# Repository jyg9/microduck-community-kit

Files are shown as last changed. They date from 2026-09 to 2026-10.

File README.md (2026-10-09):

# 用于Microduck复刻的一些PCB补充

> 这不是官方Microduck仓库，<a href="https://github.com/pollen-robotics/microduck">官方仓库</a>在这里，感谢他们开源。本项目是复刻所需硬件PCB补充。

微信讨论群：

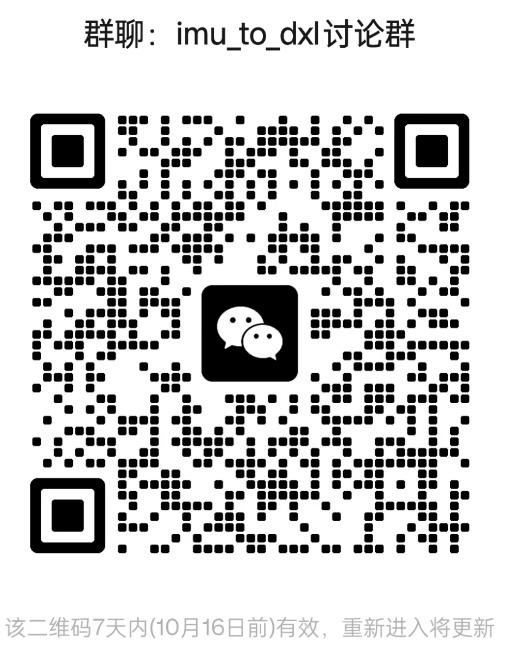
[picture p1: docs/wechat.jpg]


主要包括：
- **imu_to_dxl**：<a href="hardware/imu_to_dxl">身体传感器板</a>、<a href="firmware/v1">对应的固件</a>和<a href="firmware/v1/host">上位机测试软件</a>。特点：高度接近原版设计、高可靠设计、固件可在线升级。
- **banana_pcb**：<a href="hardware/banana_pcb">电池上方的转接小板</a>
- **dxl_hub**：<a href="hardware/dxl_hub">鸭鸭身体中的集线器板</a>
- **飞特舵机调试软件**：<a href="software/hls_servo_debugger">飞特舵机调试软件</a>
- **microduck_feetech**：<a href="https://github.com/jyg9/microduck_ft1910">官方机器人软件（robotd 等）的飞特舵机适配版</a>——官方 `microduck` 的完整参考源码，基于0.16.0打上飞特总线补丁，IMU适配本仓库，可直接编译运行；

接线图：
```text
                               🦆 头部 (Head)
                                    │
                                    │ 舵机线
                                    ▲
 🔋 电池 (Battery)            ┌───────────┐
      │                      │           │
      │ 香蕉头                │  dxl_hub  │
      ▼                      │  (腹部)    │
 🍌 banana_pcb ─────────────>│           │
      (正负电源线)             └─┬───┬───┬─┘
                                │   │   │
                 ┌──────────────┘   │   └──────────────┐
                 │ 舵机线            │ 舵机线            │ 舵机线
                 ▼                  ▼                  ▼
            🦿 左腿            ⚖️ IMU            🦿 右腿
                             (imu_to_dxl，跨部内)
```

如需要编译固件，克隆的时候需要增加--recurse-submodules参数，否则不会下载GDLib：
```bash
git clone --recurse-submodules https://github.com/jyg9/microduck-community-kit.git
```

固件升级方法：
- 1、SFTP复制本项目<a href="firmware/v1/host">主机工具</a>下的`upgrade.py`、`package.py`、`bus.py`到目标电脑。目标电脑可也是鸭子后台，也可以是电脑接USB转舵机TTL。
- 2、从项目Releases下载编译好的固件，两个文件`gd32f303cc_imu_to_dxl_slot_a.ipkg`和`gd32f303cc_imu_to_dxl_slot_b.ipkg`，同样复制到目标电脑。
- 3、执行升级指令：
```bash
# 看目前节点版本号等信息，需不需要升级，提示缺依赖使用pip3 install <包名>安装
./upgrade.py status build/gd32f303cc_imu_to_dxl_slot_a.ipkg

# 升级指令，使用自动识别串口
./upgrade.py upgrade gd32f303cc_imu_to_dxl_slot_a.ipkg

# 升级指令，指定一些参数（高级，与上面二选一）
./upgrade.py upgrade gd32f303cc_imu_to_dxl_slot_a.ipkg --port /dev/ttyS2 --baud 1000000 --protocol auto --yes

# 如果提示slot_a占用，更换上面文件名为slot_b，目前脚本还不是十分智能

# 再检查升级后节点版本，版本号一致就是升级成功
./upgrade.py status
```

## 其他说明
 - 项目主要使用了中国国内易于采购的飞特1910舵机，同时兼容原版XL330
 - 本项目在Linux平台开发，不能保证其他平台兼容性
 - 硬件是纯手工绘制，软件全部由AI编写和调试，已经消耗1G+ Token
 - imu_to_dxl如有需要，可在<a href="https://item.taobao.com/item.htm?ft=t&id=1085185543605">我的店铺</a>购买。
 - 如果觉得项目不错，欢迎小额打赏😀，或者点个星⭐再走？

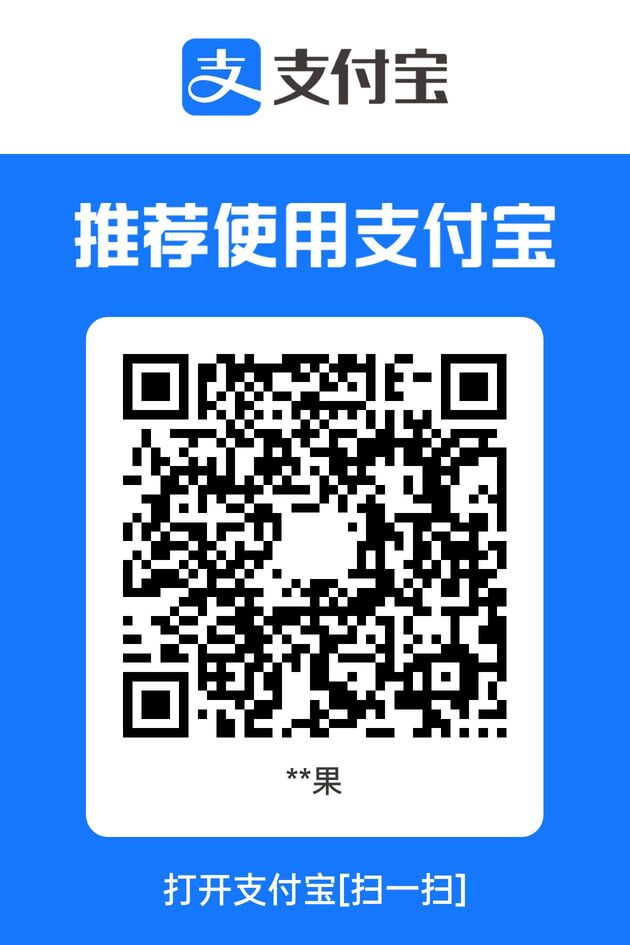
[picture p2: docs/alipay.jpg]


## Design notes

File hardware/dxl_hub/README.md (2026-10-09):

# "dxl_hub" 电力与数据分发板子

> "dxl_hub" 固定在机器鸭身体中舵机上方的板子。用于把电池电力分配到左右腿、头部和IMU。对单总线串口数据信号进行合并。

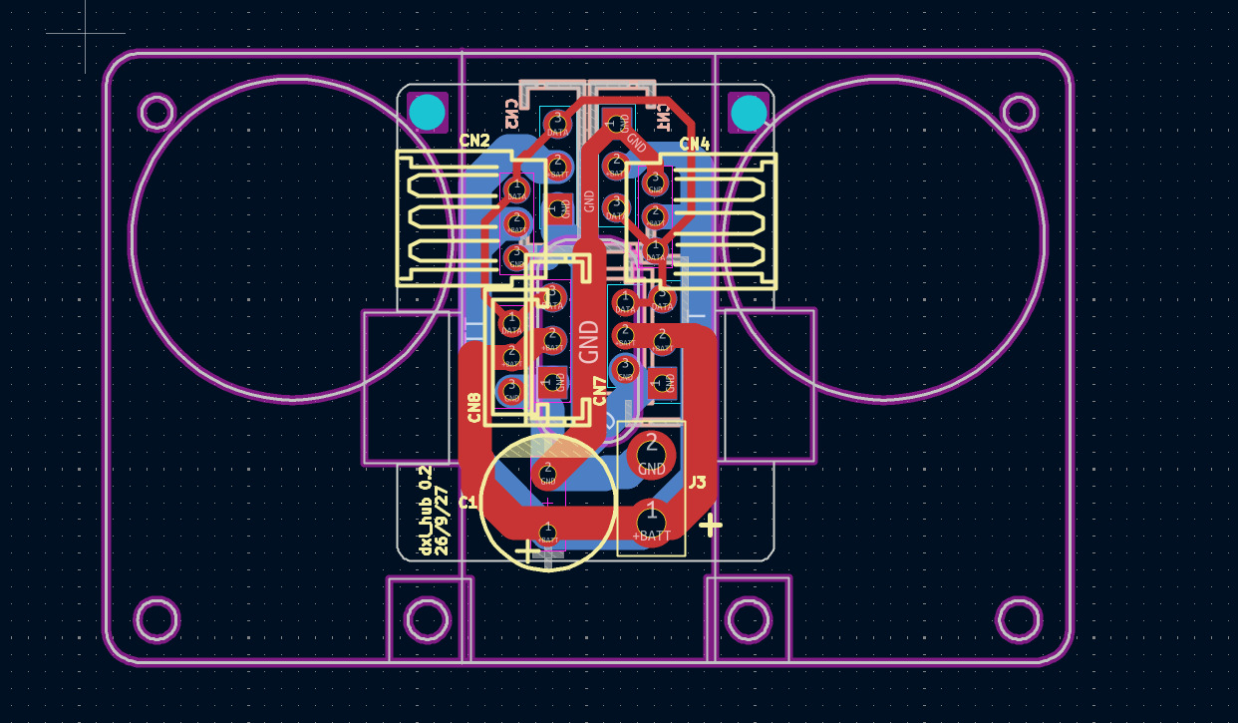
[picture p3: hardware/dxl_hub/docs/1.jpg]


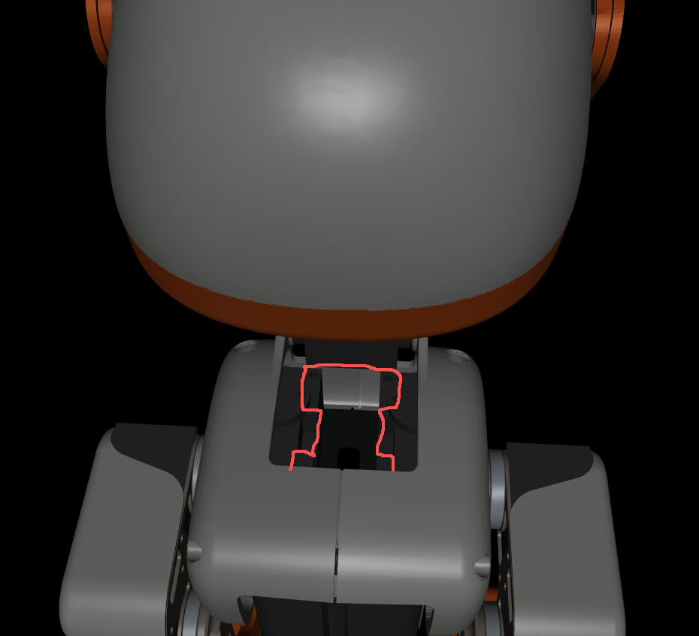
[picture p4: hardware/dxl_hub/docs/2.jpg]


 - 根据需要焊接飞特1910舵机接口或XL330舵机接口，二选一。
 - 三个焊接在背面（两腿+IMU），一个正面（脖子）。
 - 注意：固定到舵机的两颗螺丝，最好用平头，不要用圆头，会有干涉。
 - 插座参考型号：
  - XL330用：B3B-EH-A(LF)(SN)，立式，
  - 飞特1910立式用：A2007WV-3P

## 其他信息
 - 使用KiCAD 9设计。

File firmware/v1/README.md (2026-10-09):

# imu_to_dxl v1 — GD32F303CC 固件

复刻官方未开源的 `imu_to_dxl` 板：把 IMU 姿态数据做成**电机总线上的一个从站节点**，
让机器人控制软件（`microduck` 的 `robotd`）用**同一次 sync_read** 同时拿到 IMU 与全部舵机状态，
主机侧不需要任何额外轮询或融合。

* 主控：GD32F303CC（LQFP48，256 KB Flash / 48 KB SRAM，12 MHz 晶振 → 120 MHz）
* 目标板：`elec_imu_to_dxl/imu_to_dxl`，**PCBA 已回板并烧写**（bootloader + slot A），
  节点 ID 200 挂在 1 Mbps 半双工伺服总线上（USART1，PA2/PA3）
* 真板传感器：**LSM6DSV16X**（SPI0：PA4=CS / PA5=SCK / PA6=MISO / PA7=MOSI，INT1/INT2 = PB0/PB1），
  由 `IMU_USE_SPI=1`（默认）选 `src/imu_spi.c` + `src/lsm6dsv16x.h`；`=0` 时回到模拟器 `src/imu_sim.c`
* 台架拓扑：PC 经 USB 串口适配器接**电机总线**（USART1，PA2/PA3；15 颗 HD-1910-C001：右腿 10-14、
  左腿 20-24、颈/头/嘴 30-34），适配器通常枚举成 `/dev/ttyACM0`（换 USB 口后先 `ls /dev/ttyACM*` 确认）；
  调试口是 CH340 的 `/dev/ttyUSB*`（USART0，PB6/PB7，115200，**只输出 `DBG_*` 日志、不承载任何协议**）
* 两种协议：**Dynamixel 2.0**（ID 200，地址 124）与**飞特 SCS/HLS**（ID 200，地址 56），节点自动识别
* 上位机：`host/`（本地网页版，3D 姿态 + 实时瀑布流 + 抖动/偏移统计）

> 相关文档
> * `docs/dynamixel_slave.md` —— Dynamixel 从站实现细节与寄存器表（含 2.0 字节填充）
> * `docs/flash_layout.md` —— Flash 分区 / bootloader / 总线升级协议设计（待实现）
> * `docs/lsm6dsv16x_driver_spec.md` —— 真 LSM6DSV16X 驱动规格（含 §8.1 CONVERGE 实现状态）
> * `docs/bus_timing_borrow_plan.md` —— 总线时序风险分析 + 借鉴计划（**已实施**；真机缺陷见 §4.6，真机验证见 §7）
> * `patches/README.md` —— 官方 `microduck` 仓库飞特补丁说明（补丁文件同目录；原名 `microduck_feetech_patch.md`，`2fc4731` 改名）
> * `../../software/microduck_feetech/` —— 打好该补丁的官方 `microduck` 完整源码（可直接编译运行 `robotd`）
> * `../../docs/飞特通讯协议说明.md` —— 飞特协议完整说明
> * `host/README.md` —— 上位机使用说明

---

## 1. 当前状态（诚实清单）

| 功能 | 状态 | 验证方式 |
|---|---|---|
| 系统时钟 120 MHz（12 MHz 晶振） | ✅ | 上板运行（LED 心跳 + 串口 banner） |
| Dynamixel 2.0 从站（PING/READ/WRITE/REG/SYNC_READ/SYNC_WRITE/**FAST_SYNC_READ 0x8A**/BULK_READ/RESET/REBOOT/CLEAR） | ✅ | `host/tools/test_protocols.c` 逐字节比对 rustypot 参考向量；`host/tools/rustypot_check/` 再用**真的 rustypot 1.8 解析器**对拍 |
| Dynamixel 2.0 `0x8A` 聚合应答（`ID=0xFE`、不填充、逐段累积 CRC、按字节数让位） | ✅ | C 测试（含 e-manual 32 字节向量与 `FF FF FD` 反证）+ 真机 `host/tools/fast_sync_read_check.py`（19 项，见 `docs/imu_to_dxl_protocol.md` §11(c2) 与 `docs/bus_timing_borrow_plan.md` §7.8）；真 XL330 同总线未验证，见 `docs/imu_to_dxl_protocol.md` §15.5 第 11 项 |
| Dynamixel 2.0 字节填充（`FF FF FD`） | ✅ | 同上 + `src/stuffing.c` 单元测试（rustypot 1.6 会解填充） |
| 飞特 SCS/HLS 从站（PING/READ/WRITE/REG/ACTION/RECOVERY/**REBOOT 0x08**/RESET/CAL/SYNC_READ/SYNC_WRITE） | ✅ | 同上 + `host/bus.py` 自检 |
| 协议自动识别 + 粘滞 + 可锁定 | ✅ | `host/tools/bus_smoke.py`（上板后可跑） |
| 模拟 IMU（7 种模式，四元数与陀螺自洽） | ✅（`IMU_USE_SPI=0`） | C 测试：陀螺/四元数导数一致性、半精度、安装矩阵往返 |
| **真 LSM6DSV16X SPI 驱动（`src/imu_spi.{c,h}` + `src/lsm6dsv16x.h`）** | ✅ 已实现 + 真机验证 | `bus_smoke.py` 真传感器路径 + `host/tools/sensor_probe.py`；见 §8.6 |
| **`IMU_USE_SPI` 构建开关（默认 1 = 真驱动，0 = 模拟器）** | ✅ | `src/board.h`、`CMakeLists.txt` |
| 寄存器镜像（XL330 控制表 + HLS 内存表 + 厂商窗口） | ✅ | C 测试 + 上位机读写 |
| 片上温度 / 实时 tick / 状态位 | ✅ | 寄存器读取 |
| 调试串口（可宏关闭、运行时可调级别） | ✅ | 上板（banner + 2 s 周期统计） |
| USART1 电机总线 + USART0 只输出日志的调试口 | ✅ | 见 §5；协议与升级只走总线（PC 侧通常 `/dev/ttyACM0`）；镜像口是默认关闭的台架选项 |
| 配置存 Flash（ID/波特率/模拟参数） | ✅ | `src/dev.c`（最后一页 + CRC16） |
| 上位机网页版（3D + 瀑布流 + 统计 + 录制 CSV） | ✅ | HTTP/WS 集成测试 + 前端桩测试（见 §7） |
| **bootloader（32 KB）+ A/B slot 启动决策** | ✅ 已实现 | `host/tools/test_boot.c`（决策表全表）+ 真机启动 A/B/回滚 |
| **电机总线串口升级（块 CRC + 两段镜像 CRC32 + trial/回滚）** | ✅ 已实现 | `host/tools/test_boot.c` + `host/tools/test_upgrade.py`（pty 端到端）+ 真机 3 次升级 |
| **Linux 升级工具（包校验 / 版本比较与提示 / 升级 / 回读）** | ✅ 已实现 | `host/upgrade.py`，见 `docs/upgrade.md` |
| **sync_read 位次仲裁（答在自己的槽里）** | ✅ 已实现 + 真机验证 | 真机 1/2/3 个前导 ID → +339/+676/+1001 µs；`test_protocols.c` 的 `bus_arb` 用例 |
| **中断解析 + DMA 应答（T_resp 有界）+ 原子遥测发布** | ✅ 已实现 + 真机验证 | 双协议冒烟 2555 次轮询、0 超时 0 坏帧；`bus_arb`/`telem_pack` 主机用例 |
| **FeeTech 15 字节契约块（56）+ 20 字节诊断块（native 128 / ft6 124）** | ✅ 已实现 + 真机验证 | `bus_smoke.py`：56/15、byte14=0、计数递增、与别名一致（native 128，ft6 196） |
| microduck 飞特补丁 | ✅ 已编译 + 单测（93 项） | `patches/microduck-feetech.patch` |

**已在真硬件上实测**：协议（两种）、bootloader 启动决策、总线升级（3 次，含 trial
自确认与 3 次未确认回滚）、升级前后协议冒烟全过 —— 记录见 `docs/upgrade.md` §8。
时序改造（位次仲裁 / 中断+DMA 应答 / 契约块）有一轮真机验证（`docs/bus_timing_borrow_plan.md` §7）；
真 PCBA + 真 LSM6DSV16X + 15 颗舵机的一轮见本文 §8.6 与计划文档 §7.6/§7.7。

**真硬件已验证（2026-09-25）**：真 LSM6DSV16X（`WHO_AM_I`=0x70、SPI0 mode 0 @7.5 MHz、
静止 996–997 mg、`|q|`=1.0000、四元数重力 vs 加速度 0.05–0.12°、陀螺零偏 (−0.97,+0.16,+0.73) dps）、
与 15 颗舵机共总线（16 ID `sync_read` 150/150 扭矩开/关、背靠背 200/200）、
真机联调修掉的三个固件缺陷（回声窗口 / µs 时钟回绕 / SFLP CONVERGE，见计划文档 §4.6）。

**仍未在真硬件上验证的部分**：绝对 T_resp（要示波器/逻辑分析仪，宿主 USB 时间戳只到 ~0.3 ms）；
本节点排在 `sync_read` ID 列表中间/末尾时的让位（运行时 200 固定第 0 位）；
满槽 96 KB 升级与擦除中途掉电演练。（主机侧 `robotd` 突发截断曾列在此处，**2026-10-02 已修**：
删 `tcdrain` + `BURST_IDLE` 2 → 4 ms，见 `docs/bus_timing_borrow_plan.md §7.7`。）

---

## 2. 硬件与引脚

| 引脚 | 功能 | 说明 |
|---|---|---|
| PA2 / PA3 | USART1 TX / RX | **电机总线**（单线半双工）。节点与 15 颗舵机共用，全部寄存器协议流量与现场升级只在这里（PC 侧 USB 串口适配器，通常 `/dev/ttyACM0`）。方向控制由硬件从 TX 自动产生（原理图里的 `TXD_EN`，Q1+R28/R29/C22），固件不控制任何 GPIO |
| PA4 | SPI0_NSS | IMU 片选（低有效）；`IMU_USE_SPI=1` 时由 `src/imu_spi.c` 驱动，传输间保持高 |
| PA5 / PA6 / PA7 | SPI0_SCK / MISO / MOSI | IMU SPI，`IMU_USE_SPI=1` 时是 LSM6DSV16X 总线（mode 0 @ 7.5 MHz）；`=0` 时浮空不用 |
| PB0 / PB1 | IMU INT1 / INT2 | LSM6DSV16X 上拉输入；驱动轮询，但已把 FIFO 水位/溢出路由到 INT1，留给将来中断或示波器 |
| PB6 / PB7 | USART0 TX / RX | **只输出调试日志**的串口（CH340，PC 侧 `/dev/ttyUSB*`，115200），不解析、不应答任何协议帧；`BUS_MIRROR_ENABLE=1` 时才是台架镜像口（见 §5） |
| PB5 | 状态 LED（开发板） | 1 Hz 心跳；5 s 没收到总线帧则 8 Hz 闪（提示"没有主机在说话"） |

时钟：`(HXTAL / 2) * 20 = 120 MHz`。**注意** GD32 官方 `system_gd32f30x.c` 默认按 8 MHz 晶振
硬编码 `RCU_PLL_MUL30`，在 12 MHz 板上会算成 180 MHz 而卡死；本工程自带一份可选时钟源的副本
（`src/system_gd32f30x.c`），`HXTAL_VALUE` 也必须通过 CMake 传成 12 MHz，否则波特率会错。

---

## 3. 遥测块（与官方板一致）

20 字节诊断块，两种协议的**内容**相同，但 FeeTech 的 56 处只暴露前 15 字节（见 §4）：

| 字节 | 内容 | 单位 |
|---|---|---|
| 0~5 | 陀螺 x/y/z，i16 小端 | ±500 dps，**17.5 mdps/LSB** |
| 6~11 | 四元数 x/y/z，IEEE half（binary16） | `w = √(1-x²-y²-z²)` |
| 12~17 | 加速度 x/y/z，i16 小端 | ±4 g，0.122 mg/LSB |
| 18 | 采样计数（u8，回绕） | 100 Hz |
| 19 | 状态位 | `0x01` SFLP 有效（本块带四元数）/ `0x02` 计数回绕 / `0x04` 陀螺饱和 / `0x08` 传感器错误 / `0x10` 模拟数据 / `0x20` 冻结 / `0x40` 配置未保存 / `0x80` 融合算法**正在运行**（`FUSION_OK`，不等于已收敛） |

控制环只读**前 12 字节**（陀螺 + 四元数 xyz）——这正是官方板"与舵机共用地址、塞进同一事务"的做法。

**FeeTech 侧的"契约块"（重要）**：真舵机在地址 56 起只答 **15 字节**
（位置/速度/负载/电压/温度/状态/移动/电流），而运行时的 `sync_read` 对 IMU 节点和 15 颗舵机
用的是**同一个长度**。所以本节点在 56 处也回答 15 字节：
`12 字节控制块 + 采样计数(12) + 状态位(13) + 保留 0(14)`（`src/telem_pack.c`），
**加速度搬到 20 字节诊断块的别名**（native 在 128；ft6 人格在 196，见 `docs/imu_to_dxl_protocol.md` §16）。选 15 而不是 20 是量出来的：每多 5 字节 × 16 个设备
就要多约 0.8 ms 总线时间（见 `docs/bus_timing_borrow_plan.md` §2、§7）。

**坐标系**：板子安装使 `躯干系 = [+raw_z, +raw_y, −raw_x]`（绕 Y 轴 +90°）。
固件上报的是**芯片系**数据，主机用 `microduck` 的 `DEFAULT_MOUNT = [1/√2, 0, 1/√2, 0]`
左乘/右乘还原（`q_trunk = q_raw ⊗ mount⁻¹`，`ω_trunk = mount · ω_raw`）。
调试时可用厂商寄存器 `REPORT_FRAME=1` 让固件直接上报躯干系（主机就不要再转）。

**已知偏差**：真板存在约 5° 的系统性 pitch 偏置，由 runtime 在源头校正（见 `microduck` 注释）。
上位机 3D 视图会显示重力与"世界竖直"的夹角，可用来测这个偏置。

---

## 4. 两种协议下的地址映射

| | Dynamixel 2.0 | 飞特 SCS/HLS |
|---|---|---|
| 帧结构 | `FF FF FD 00 ID LEN_L LEN_H INST ... CRC16`（ROBOTIS CRC-16，**含帧头**；状态帧带 `0x55` 标记；**参数区字节填充**） | `FF FF ID LEN INST [ADDR] DATA ~SUM`（8 位取反和；无填充） |
| 节点 ID | 200（寄存器 7，可改并持久化） | 200（寄存器 5，可改并持久化，禁止 0xFD） |
| 遥测块地址 | **124**（`present_pwm` 起 20 字节，前 12 是控制环要的；两种 FeeTech 人格下都一样） | **56**（`PRESENT_POSITION_L` 起 **15** 字节：12 控制 + 计数 + 状态 + 保留 0）；完整 20 字节诊断块在 **128**（native）/ **196**（ft6） |
| 波特率 | 1 Mbps（寄存器 8 = 3） | 1 Mbps（寄存器 6 = 0） |
| 每次调度读的地址/长度 | `124` / 12（主机可读 20 拿诊断尾部） | `56` / **15**（与 15 颗舵机同一次 `sync_read`，长度必须对所有设备成立） |
| 厂商配置窗口 | **148~167**（20 字节） | **160~179**（同一张表） |
| 设备语义 | 状态返回级别(68)、只读区拒绝写入 | 应答状态级别(8，默认 1)、锁标志(55，默认 0=可持久化)、角度限位/死区/偏移等 |
| 只读信息 | 型号 1200（`0x04B0`）、固件版本 0x10 | 固件版本 1.0（寄存器 0/1）、型号 `0x4D49`（'I','M'，**故意不是舵机型号**） |
| 应答 STATUS 字节 | 按协议（`DXL_ERR_*`，rustypot 会解码） | **恒 0**（飞特工具会把非 0 当舵机故障）；最近一次内部错误放厂商窗 `V_LAST_ERR`(179) |
| 5 V / 诊断 | 144~146（电压、温度） | native：128~147（诊断块 + 别名）；ft6：124~143（诊断块）+ 196~215（别名）；71~75 不参与契约，保持 0 |

飞特侧另外按厂商手册实现了两个容易被忽略的语义：寄存器 8（应答状态级别，写 0 后写指令执行但静默、
读指令仍应答）与寄存器 55（锁标志，加锁时写入仍生效但不持久化——手册里它是"是否掉电保存"，不是"是否允许写"）。
两项都有上板回归（`host/tools/bus_smoke.py` 的 `device semantics` 段）。

**协议自动识别**：一帧的第 3 字节为 `0xFD` → Dynamixel 2.0；否则 → 飞特。
成功应答一种协议后，该端口 100 ms 内只认这种协议（`BUS_PROTO_STICKY_MS`），
避免把数据里的 `FF FF <本机ID>` 误判；厂商寄存器 `PROTO_LOCK`（0 自动 / 1 仅 DXL / 2 仅飞特）可强制。

**位次与应答时序（实测，见 `docs/bus_timing_borrow_plan.md` §7）**：真舵机在 `sync_read`
里会为**每一个排在它前面的 ID** 等一个"应答槽"（实测 ≈295 µs，前导设备缺席也照样占一槽）。
本节点在 ID 列表里的下标 k > 0 时，会先让出 k 个槽再应答（`src/bus_arb.c`）；运行时 IMU 节点
固定排第 0 位，所以那条热路径是"收完指令立刻发"。应答的解析在 USART 中断里、
发送走 **DMA**（USART0_TX = DMA0 CH3，USART1_TX = DMA0 CH6），因为排在后面的设备
只留 ≈295 µs，主循环给不出这个上界。

**FeeTech `0x08` REBOOT（实测补充，见计划文档 §1.7）**：这颗 HD-1910（fw 3.46）**支持** 0x08——
**不应答**、约 **823 ms** 回来、ID/波特率/模式/锁/OFS 全保留、**RAM 增益(50/51)回落到 EEPROM(21/22)**
（正是 `RobotIo::reboot` 契约要的语义）。本节点的飞特人格据此实现 0x08（不应答地重启，
应用与 bootloader 共用 `dev_request_reboot()`）；主机补丁的 `reboot()` 也从"明确不支持"
改成"先写扭矩 0、发 0x08、不等应答立即返回"。

---

## 5. 调试口（只输出日志）与电机总线

**电机总线是 `USART1`（PA2/PA3）**：节点和 15 颗舵机共用它，单线半双工；所有寄存器协议流量
（Dynamixel 2.0 / 飞特）与**现场升级**都只在这条总线上发生，别处没有。PC 侧是 USB 串口适配器，
通常枚举成 **`/dev/ttyACM0`**（ACM 编号跟着适配器枚举走，换 USB 口/插别的设备后先
`ls /dev/ttyACM*` 确认）；`host/`、`./build.sh smoke` 与 `host/upgrade.py` 都默认用它。

**调试口是 `USART0`（PB6/PB7）**：CH340，PC 侧是 `/dev/ttyUSB*`，115200，**只输出日志**，
不承载任何协议——它不解析、也不应答协议帧，所以终端上敲的东西不会被当成总线帧。
日志行以 `#` 开头、ASCII 里没有 `0xFF`（主机分帧器可以安全地在文本里重新同步）。

* `BUS_MIRROR_ENABLE`（`src/board.h`、`CMakeLists.txt`）现在**默认 0**，上面就是默认行为。
* 只有在"开发板上电机总线还没接"的**台架**场景才把它设为 1：此时 `USART0` 临时兼作第二个
  协议口（1 Mbps，波特率编码见 §6 的 `MIRROR_BAUD`），方便一块板子上同时看调试文本与协议。
  注意这时的 `USART0` **什么都能做，包括升级**——协议层不区分端口。所以升级工具
  `--port` 默认指向电机总线（`auto` 会打印它选了哪个设备，见 `docs/upgrade.md` §4.5），
  不要指到调试口上去。
* 升级端口由**工具**负责选对：默认 `--port auto` **逐个探测** `ttyACM0-1`、
  `ttyUSB0-5`、`ttyS2` 里存在的设备，取第一个真的能应答节点的那个并打印它选了谁
  （存在的 `ttyUSB*` 不会被按名字排除：它既可能是总线适配器，也可能是调试口，
  按"能不能应答"判断）；同时**拒绝和另一个主机抢端口**（机器人上那是 robotd，
  工具会打印 stop/upgrade/start 三行提示）。见 `docs/upgrade.md` §4.5。

`./build.sh` 现在会在配置之后打印**有效的缓存选项**（`APP_SLOT APP_VERSION_STR BOOT_ENABLE
DBG_ENABLE BUS_MIRROR_ENABLE IMU_USE_SPI`），`BUS_MIRROR_ENABLE=1` 时还会加一条 NOTE。
CMake 的缓存会跨源码更新保留旧值，所以老的 `build/` 目录可能仍是台架镜像构建：
如果摘要里是 1，用 `./build.sh clean`（或 `-DBUS_MIRROR_ENABLE=0`）重新配置。

**调试口的物理引脚**（这块 PCBA 上是一个 4 pin 排针 **H1**；网表见 `hardware/imu_to_dxl`）：

| H1 引脚 | 信号 | 说明 |
|---|---|---|
| 1 | `+3.3V` | |
| 2 | `GND` | |
| 3 | `DEBUG_RX` | **PB7**，经串阻 R10，R7 上拉到 3.3V |
| 4 | `DEBUG_TX` | **PB6**，经串阻 R11 |

**PC 侧适配器的 TX 必须接到 H1-3**。只接 GND + TX 的"两根线"接法能读到日志（TX 一路是通的），
但节点收不到任何字节——日志里 `uart0 rx=0` 就是它的表现，`BUS_MIRROR_ENABLE=1` 的台架镜像模式
也就无从谈起（这一点在真板上实测确认过）。

---

## 6. IMU：真驱动与模拟器

`IMU_USE_SPI`（`src/board.h`、`CMakeLists.txt`，默认 **1**）选择传感器来源：

* **1 = 真 LSM6DSV16X**：`src/imu_spi.c` + `src/imu_spi.h` + `src/lsm6dsv16x.h`，
  SPI0（PA4–PA7），mode 0 @ 7.5 MHz，芯片自己做 SFLP 融合；`src/imu.c` 是门面并拥有 10 ms 采样网格。
* **0 = 模拟器**：`src/imu_sim.c` 用**同一条角速度**既积分四元数又生成陀螺计数，
  保证上报的陀螺与四元数严格自洽（这样才能真正验证上位机的 3D 视图与瀑布流，而不是看随机数）。

模拟器模式（仅 `IMU_USE_SPI=0` 的构建生效）：

| `SIM_MODE` | 名称 | 用途 |
|---|---|---|
| 0 | static | 静止 + LSB 级噪声：看抖动底噪 |
| 1 | sine | 三轴正弦（默认）：看 3D 姿态与瀑布流是否正常 |
| 2 | drift | 慢速偏航 + 注入陀螺偏置：看"偏移/漂移" |
| 3 | noise | 宽带陀螺噪声：看抖动与统计 |
| 4 | spin | 快速自转 |
| 5 | sflp-wait | 陀螺正常但四元数字节全 0：验证"保持上一有效值 / ready 门控" |
| 6 | frozen | 每次读出完全相同：验证 `microduck` 的 stale 检测 |

厂商窗口（20 字节，DXL 148 / 飞特 160）：

| 偏移 | 名称 | 读/写 | 说明 |
|---|---|---|---|
| 0~1 | MAGIC | RW | `0x4D49`（'I','M'）；写窗口时用于判断有效性 |
| 2 | CMD | W | 1 保存配置 / 2 恢复出厂 / 3 重启 / 4 重启运动模型（执行后自动清 0） |
| 3 | SIM_MODE | RW | 上表 0~6 |
| 4~5 | SIM_AMP | RW | 幅度千分比 100~5000（默认 1000） |
| 6~7 | SIM_FREQ | RW | 频率千分比 100~5000（默认 1000） |
| 8 | REPORT_FRAME | RW | 0 芯片系（默认，与真板一致）/ 1 躯干系 |
| 9 | PROTO_LOCK | RW | 0 自动 / 1 仅 Dynamixel / 2 仅飞特 |
| 10~15 | GYRO_BIAS_X/Y/Z | RW | i16，直接叠加到上报的陀螺原始计数（注入偏移或在线标定） |
| 16 | MIRROR_BAUD | RW | USART0（调试口 / 台架镜像口）波特率编码（飞特编码表）。`BUS_MIRROR_ENABLE=0` 时 USART0 固定 115200 调试口；此寄存器与电机总线（USART1）无关 |
| 17 | DBG_LEVEL | RW | 0 关 / 1 仅错误 / 2 启动+2 s 统计（默认）/ 3 每帧跟踪 |
| 18 | STATUS | R | bit0 配置未保存 / bit1 来自 Flash / bit2 使用模拟数据 |
| 19 | LAST_ERR | R | 最近一次被拒绝的协议操作（`DXL_ERR_*`）。应答 STATUS 恒 0，所以原因只能从这里问 |

配置（ID / 波特率 / 模拟参数）写入后**先等寄存器写入平静 500 ms，再等总线安静 1.5 s**，
才落 Flash 最后一页（`0x0803F800`，`CFG_FLASH_ENABLE=0` 可关）——
因为擦一页 Flash 会让内核（以及 USART 中断）停顿几十毫秒，在机器人持续轮询时保存会吃掉一个控制周期。
显式的 `CMD=1`（保存）是立即写，主机需要容忍那一次读超时。`CMD=2` 恢复出厂。

厂商窗口的 `STATUS`(18) 与 `LAST_ERR`(19) 可以写（整窗口 20 字节一次写入不会被拒），但写入无效——
主循环发布寄存器镜像时（`dev_refresh()`）会用真实状态覆盖它们。**寄存器镜像现在由主循环发布，
读取本身不再触发刷新**：读发生在 USART 中断里（见 §4 的时序段），那里不能做 ADC 转换或重写厂商窗。
发布在一段很短的临界区里完成，所以中断读到的是"整块新"或"整块旧"，不会读到半新半旧的四元数。

---

## 7. 编译、烧录与测试

```bash
cd v1

# 1) 构建（arm-none-eabi-gcc + cmake，无需网络）
./build.sh

# 1b) 1) 里的构建已经是 FT6 人格（默认）+ 本板朝向补偿，直接给 R17 机器人用。
#     要出 native（社区主机）镜像，另用一个 BUILD_DIR 显式指定：
BUILD_DIR=build-native EXTRA_CMAKE_ARGS="-DFEE_IMU_PERSONALITY=native" ./build.sh

# 2) 烧录（J-Link，设备名必须是 GD32F303CC，不能带封装后缀 T6）
./build.sh flash              # APP_SLOT 镜像（开发板构型，会覆盖 bootloader 区）
./build.sh flash-pair a       # 量产构型：一次擦除 + bootloader + slot A（推荐）
./build.sh flash-boot         # 只更新 bootloader（整片擦除）
./build.sh flash-slot b       # 只替换 slot B（不擦除，保留 bootloader）
./build.sh erase / reset

# 3) 全部主机测试（纯 gcc + Python，不需要硬件）
./build.sh test
#    -> CRC 对拍、两个协议从站、bootloader 决策表/flash 策略/升级状态机（9500+ 断言）
#    -> 寄存器镜像：native 金标逐字节比对 + ft6 人格布局 + 两种人格 DXL 镜像相同
#    -> 升级包格式 + 升级工具 pty 端到端（173 断言）+ 编解码/服务自检
host/tools/run_c_tests.sh                          # 只跑 C 部分
../.venv/bin/python host/tools/test_upgrade.py     # 只跑升级工具端到端

# 4) 上板协议冒烟测试（需要串口；真/模拟两条路径，脚本读 TELEM_FLAG_SIMULATED 自动选）
./build.sh smoke
BUS_PORT=/dev/ttyACM0 BUS_BAUD=1000000 ./build.sh smoke      # 电机总线口（先 ls /dev/ttyACM* 确认编号）
BUS_PORT=/dev/ttyUSB0 BUS_BAUD=1000000 ./build.sh smoke      # 仅台架镜像构建（BUS_MIRROR_ENABLE=1）

# 4b) 真舵机只读探针（PING/READ/SYNC_READ，绝不写；见 docs/bus_timing_borrow_plan.md）
./host/tools/py.sh host/tools/servo_probe.py --port /dev/ttyACM0 --repeat 21

# 4c) 真 LSM6DSV16X 只读表征探针（四元数/加速度/重力夹角/零偏/SFLP 重启；见 §8.6）
./host/tools/py.sh host/tools/sensor_probe.py --port /dev/ttyACM0

# 4d) Fast Sync Read（0x8A）验收：本机在第 0 位 / 第 1 位 / 未被点名三种位置
./host/tools/py.sh host/tools/fast_sync_read_check.py --port /dev/ttyACM0
./host/tools/py.sh host/tools/fast_sync_read_check.py --self-test       # 不需要硬件

# 4e) 与官方 rustypot 解析器对拍（需要 Rust 工具链，故不在 ./build.sh test 里）
cd host/tools/rustypot_check && cargo run --release && cd -

# 5) 现场升级（详见 docs/upgrade.md）
./build.sh status  build/gd32f303cc_imu_to_dxl_slot_b.ipkg    # 需不需要升级？
./build.sh upgrade build/gd32f303cc_imu_to_dxl_slot_b.ipkg --yes
./host/upgrade.py verify <pkg>                                # 只校验包

# 6) 打开上位机（浏览器访问 http://127.0.0.1:8081）
./build.sh host
```

可选编译项（`EXTRA_CMAKE_ARGS` 或 `-D` 传入）：

| 变量 | 默认 | 说明 |
|---|---|---|
| `APP_SLOT` | 0 | 0 = 链接到 0x08000000（开发板，无 bootloader）；1/2 = A/B slot（并设置 VTOR） |
| `BOOT_ENABLE` | 1 | 1 = 同时构建 bootloader 与 A/B 两个 slot 镜像 |
| `APP_VERSION_STR` | 按人格 | 打进镜像头与升级包的版本号（`major.minor.patch`，只能是数字）。native 默认 `1.5.1`、ft6 默认 `1.6.0`；两种人格必须不同，否则升级工具会拒绝或静默替换人格 |
| `DBG_ENABLE` | 1 | 0 = 完全去掉调试输出代码 |
| `BUS_MIRROR_ENABLE` | 0 | **默认 0**：USART0 只做调试口（只输出日志）。1 = 台架选项（开发板尚未接电机总线时让 USART0 兼作协议口），升级会话仍只在电机总线上开放 |
| `IMU_USE_SPI` | 1 | 1 = 真 LSM6DSV16X（`src/imu_spi.{c,h}` + `src/lsm6dsv16x.h`）；0 = 模拟器（`src/imu_sim.c`） |
| `FEE_IMU_PREMOUNT` | `0,0,0,1`（ft6） | ft6 人格专用：给飞特侧 12 个控制字节加的**芯片系**预旋转 `"w,x,y,z"`。默认 `0,0,0,1` = 本板 IMU 芯片相对原 FT6 节点绕封装法线翻转 180°（X、Y 反向、Z 不变），因此主机侧标定可以保持出厂值；`1,0,0,0` = 不转（与原节点同向时用）。Dynamixel 侧不受影响 |
| `FEE_IMU_PERSONALITY` | ft6 | FeeTech 侧线协议人格：`ft6` = 与 R17 主机的 FT6 节点逐字节兼容（**默认**，R17 机器人用这个）；`native` = 本仓库自己的契约。**只影响 FeeTech 侧**，Dynamixel 协议 2.0 两种人格完全相同。两种人格的镜像在总线上不通用，请各用一个 `BUILD_DIR`（详见 `docs/imu_to_dxl_protocol.md` §16） |
| `STATUS_LED_ENABLE` | 1 | 0 = 无 PB5 心跳灯 |
| `CFG_FLASH_ENABLE` | 1 | 0 = 不写 Flash（配置只存 RAM） |
| `TEMP_SENSOR_ENABLE` | 1 | 0 = 不读片内温度（固定 30 °C） |
| `SYS_CLK_SOURCE` | HXTAL | IRC8M 可绕过晶振问题 |
| `SYS_CLK_HXTAL_HZ` | 12000000 | 晶振频率，同时定义 `HXTAL_VALUE` |

当前占用（Release，`-Os`，`IMU_USE_SPI=1` 真机构建，2026-09-25 实测）：

| 目标 | FLASH | RAM |
|---|---|---|
| 应用（开发镜像，`APP_SLOT=0`） | **24036 B / 254 KB** | **8288 B / 48896 B (16.95%)** |
| 应用（slot 镜像，96 KB 槽） | **24600 B / 96 KB (25.0%)** | 8288 B |
| **bootloader** | **18764 B / 32 KB (57.3%)** | 8288 B + 8 B（`.boot_ram`） |

（以上为 2026-09-25 `./build.sh` 构建（`IMU_USE_SPI=1`）的实测大小；RAM 百分比按链接脚本的
48896 B `RAM` 区算，另有顶部 256 B `BOOTRAM` 握手区。P0/P1 时序改造那一轮的旧数字是
dev 26.1 KB / slot 26.7 KB (28%) / boot 18.7 KB (58%)，见 `docs/bus_timing_borrow_plan.md` §7.5。）

比改造前各多约 1.6–1.8 KB flash、1.1 KB RAM：应答要走 DMA（每个端口一份应答缓冲 +
一份延迟缓冲）、要 µs 级时基（DWT）、要位次状态机与契约块打包，外加真 LSM6DSV16X 驱动
（SPI0 与 CONVERGE 状态）。bootloader 也带同一套（boot 模式下协议行为与应用完全一致）。

`.boot_ram` 是 SRAM 顶部 256 字节里唯一的 8 字节握手区（NOINIT，启动代码不清），
所以 RAM 区在链接脚本里被拆成 `RAM`（48896 B）+ `BOOTRAM`（256 B）两块，并有
`ASSERT(_sp <= 0x2000BF00)` 防止栈越界踩到它。

> ⚠️ J-Link 与串口设备（电机总线 `/dev/ttyACM*`、调试口 `/dev/ttyUSB*`）在受限沙箱里不可见；
> 烧录与串口测试需要在能访问 USB 的环境执行。

### 7.1 A/B 构型与现场升级（一句话版）

量产构型是 **32 KB bootloader + 两个 96 KB 应用槽（A/B）**：bootloader 校验两个槽的
镜像头（魔数/长度/entry/两段 CRC32/板号），按 `boot_slot` 与 trial 状态选一个跳转；
新镜像先以 **trial** 启动，30 s 内没有自我确认就在 3 次尝试后**自动回滚**。
升级通过电机总线完成（复用两种协议，不新增帧类型；调试口 USART0 不参与升级，见 §5；
机器人上这条总线是 `/dev/ttyS2`，升级前先 `sudo systemctl stop robotd` 让出总线），
由 `host/upgrade.py` 驱动：

```
verify  → 校验升级包（容器 CRC32 + 镜像头 + 两段 CRC32，坏包不上线）
status  → 读节点身份窗（模式/槽/版本/镜像 CRC/启动状态）+ 版本比较与提示
upgrade → VCMD_BOOT 进 bootloader → 分块写（块 CRC + 序号 + 回读）→ UPG_END 校验
          → 重启进新镜像（trial）→ 30 s 后自确认或回滚
```

完整命令、寄存器、失败模式与实测数据见 **`docs/upgrade.md`**；设计与取舍见 `docs/flash_layout.md`。

---

## 8. 上位机

`host/` 是纯本地工具，**无第三方前端依赖**（3D 用自写 WebGL，曲线/瀑布流用 canvas）：

* 3D：板卡模型按接收到的四元数实时旋转，红色 X / 绿色 Y / 蓝色 Z 轴，地面网格，
  实测重力矢量与世界竖直对比，+Z 指向的球面轨迹（看抖动），roll/pitch/yaw 数字；
* 瀑布流 1：roll/pitch/yaw 与躯干系陀螺 x/y/z 两条滚动曲线（可锁定 Y 轴）；
* 瀑布流 2：可选量的**密度热力图**（x 轴时间滚动、y 轴数值分箱、颜色=该列命中次数）；
* 统计：每轴均值/标准差/峰峰值/最小二乘漂移斜率/极值；采样率、往返时延（中位/p95）、
  采样计数连续性、stale 连续次数与最大次数、坏帧/超时、原始状态位解码；
* 控制：串口/波特率/协议/读取方式/读取长度/轮询率、暂停、CSV 录制下载，
  以及固件厂商窗口的全部设置（模拟模式/幅度/频率/偏置/上报坐标系/调试级别/保存/恢复出厂/重启）。

自检证据：`host/tools/test_server.py` 覆盖 HTTP + WebSocket 握手、坏串口报错、暂停往返；
加 `--device /dev/ttyACM0`（电机总线）后还会在真板上验证**整链路**：连接 → 100 Hz 实时样本
（所有前端字段齐全、四元数与重力单位性）→ 统计消息（采样率 100 Hz、0 超时/0 坏帧）→ 断开。
（该轮记录里的时延 2.48 ms 是台架镜像口 `/dev/ttyUSB0` 上的数字。）
前端另有桩 DOM/WebGL 测试（协议帧解析、异常帧不崩、CSV 列数、统计单元、热力图出墨、3D 矩阵数值）。

---

## 8.5 上板验证结果（GD32F303CC 开发板 + 模拟 IMU，台架镜像口 `/dev/ttyUSB0`，1 Mbps）

固件烧录后 `host/tools/bus_smoke.py` **两种协议全部通过，0 超时、0 坏帧**：

| 项目 | Dynamixel 2.0 | 飞特 SCS |
|---|---|---|
| 型号 / 固件 | 1200 / `0x10` | **`0x4D49`（'I','M'）/ 1.0** |
| 厂商窗口 | `magic=0x4D49 mode=sine amp=1000 freq=1000 frame=chip` | 同 |
| 遥测 | 20 字节块在 124，`cnt` 递增 | **56 处 15 字节契约块**（12 控制 + 计数 + 状态 + 保留 0）+ 20 字节诊断块（native 128 / ft6 124）；ft6 人格的字节 12/13 语义不同（§16） |
| `read` 与 `sync_read` | 各 146 / 157 个样本 | 同 |
| 持续轮询 | **365 Hz，时延中位 2.71 ms、p95 2.78 ms** | **391 Hz，中位 2.53 ms、p95 2.57 ms** |
| 超时 / 坏帧 | 0 / 0 | 0 / 0 |
| 四元数、重力单位性 | `|q|=1.00000`，`|g|=1.00000` | 同 |
| 陀螺与四元数导数一致性 | **中位 2.77°** | **中位 2.08°** |
| 采样计数连续性 | 0 次跳变 | 0 次跳变 |
| 7 种模拟模式 | static/sine/drift/noise/spin/sflp-wait/frozen 现象全部符合预期 | 同 |

（`frozen` 模式确认每次读出**完全相同的块**——这正是 `microduck` stale 检测要抓的故障；
`sflp-wait` 确认四元数字节全 0 且 `SFLP_VALID=0`。）

**P0/P1 时序改造的上板验证**（细节与数据见 `docs/bus_timing_borrow_plan.md` §7）：

| 项目 | 结果 |
|---|---|
| 位次仲裁（运行时不走的那条路） | `sync_read` 的 ID 列表里放 0/1/2/3 个前导 ID（缺席）→ 往返 +0 / +339 / +676 / +1001 µs（≈330 µs/槽，含主循环派发抖动） |
| 延迟缓冲计数 | 固件统计 `bus held` 与主机发出的 60 次 k>0 事务**完全对上** |
| 15 字节契约块 | `56/15` 读回 12 控制 + 计数 + 状态，`byte14 == 0`，且计数与别名处的诊断块一致、逐帧递增（native 人格；ft6 见 `docs/imu_to_dxl_protocol.md` §16） |
| 中断 + DMA 应答 | 两种协议各自 2555 次轮询、**0 超时 0 坏帧**；Dynamixel 侧 40 个被字节填充的帧全部正确解出 |
| 间隙判据 / 回声门 | `dropped=0`、`echo` 计数正常；空闲间隔不再被误记成 `gaps` |
| 调试口与总线共用 UART0 | 有协议帧要发时日志行在字节边界让路（`uart_port_write` 逐字节检查），协议帧不会被文本插断 |

另外两项针对性的上板回归：

* **Dynamixel 2.0 字节填充在真实链路上验证**：把陀螺偏置设成让原始计数恰好出现
  `FF FF FD`（`gyro_bias=(-1,-3,0)` + static 模式），60 次读取中 **40 帧确实被填充**，
  40 帧全部被主机按 rustypot 的规则正确解填充并解出原始计数。
  （如果不做填充，microduck 侧会解析错位——这是真机会踩的坑。）
* **飞特设备语义**：寄存器 8（应答状态级别）默认 1；写 0 后写指令执行但静默、读指令仍应答；
  寄存器 55（锁标志）加锁后写入仍生效于 RAM（`register 24 = 123` 读回）。

上板过程发现并修好的三个真问题（都已回归）：
1. **厂商窗口整段写入被拒**：`STATUS`/保留字节原本被标成只读，导致 20 字节整窗口写入返回 ACCESS；
   现在这两字节可写但被忽略。
2. **协议粘滞窗口过长**：原来 1 s，主机切换协议时前 1 s 的帧被忽略；改为 100 ms（仍能挡住数据里的
   `FF FF <本机ID>` 误判），冒烟测试也加了协议切换前的静默等待。
3. **配置存 Flash 会打断总线**：擦页让内核停顿几十毫秒，机器人持续轮询时会读超时；
   现在自动保存要等"写入平静 500 ms + 总线安静 1.5 s"，显式保存才立即执行。

## 8.6 真硬件验证（真 PCBA + 真 LSM6DSV16X + 15 颗舵机，2026-09-25）

`IMU_USE_SPI=1` 构建，`flash-pair a` 烧 bootloader + slot A；节点 ID 200 经 `/dev/ttyACM1`
上真总线；`BUS_PORT=/dev/ttyACM1 ./build.sh smoke` 与
`host/tools/py.sh host/tools/sensor_probe.py --port /dev/ttyACM1` 全过。

| 项目 | 实测值 |
|---|---|
| LSM6DSV16X 身份 / SPI | `WHO_AM_I` = **0x70**，SPI0 **mode 0 @ 7.5 MHz**（`SPI_PSC_16`，APB2 = 120 MHz） |
| 量程 / 速率 | 陀螺 ±500 dps @ 120 Hz 高性能，加速度 ±4 g @ 120 Hz，SFLP game rotation vector @ 120 Hz |
| FIFO | continuous，只装 SFLP 字，水位 12 字 |
| 静止加速度模长 | **996–997 mg**（300 样本均值 997.4 mg） |
| 四元数范数 | **1.0000**（300/300） |
| 四元数重力 vs 加速度方向 | **0.05–0.12°**（mean 0.058 / max 0.115） |
| 陀螺零偏 / 每轴噪声 std | **(−0.97, +0.16, +0.73) dps** / **0.017–0.031 dps**；`gyro_bias` = **(+56, −9, −42) raw counts** |
| SFLP 重启 | `VCMD_RESET_SIM` 后 **9–13 ms** 四元数归零，**1.51–1.52 s** 后恢复非零 |
| 真驱动冒烟 | Dynamixel **1260 Hz / 3851 次轮询**（中位 0.75 ms）、FeeTech **1789 Hz / 5372 次轮询**（中位 0.52 ms），**0 超时 / 0 坏帧** |
| 与 15 颗舵机共总线 | 16 ID（200 + 10–14/20–24/30–34）一次 `sync_read`（地址 56、长 15）：**150/150 扭矩关、150/150 扭矩开、200/200 背靠背**；往返中位 8.74 / p95 8.86 / max 8.95 ms |
| 节点侧 | 每秒约 47/50 次读被应答，`echo=0 dropped=0 err=0` |

**真机联调修掉的三个固件缺陷**（现象/根因/修复/证据见 `docs/bus_timing_borrow_plan.md` §4.6）：
`uart_port.c` 的固定回声跳过吃掉下一帧帧头（改成时间窗口）、`us_time.c` 的 `us_now()`
每 35.8 s 回绕（SysTick 重锁存，真 modulo-2^32）、`imu_spi.c` 的 SFLP 重启发布未收敛姿态
（新增 CONVERGE 状态，1500 ms）。

## 9. 目录结构

```
v1/
├── CMakeLists.txt / build.sh          # 构建、烧录、测试入口
├── cmake/gd32_toolchain.cmake         # arm-none-eabi 交叉工具链
├── linker/gd32f303cc_{app,slot_a,slot_b}.ld   # slot 脚本含 .app_header + .boot_ram
├── linker/gd32f303cc_boot.ld          # bootloader（32 KB @ 0x08000000）
├── scripts/jlink_*.jlink
├── src/
│   ├── board.h                         # 引脚、时钟、协议/寄存器常量、编译开关
│   ├── main.c                          # 主循环（非阻塞）、心跳、统计、重启
│   ├── system_gd32f30x.c / systick.*    # 时钟（12 MHz 晶振）与 1 kHz 节拍
│   ├── gd32f30x_it.c                   # SysTick + USART0/1 接收 + TX DMA 完成中断
│   ├── uart_port.*                     # USART：中断收字节（回调给 bus）+ DMA 发送
│   ├── us_time.*                       # µs 时基（DWT 周期计数器）
│   ├── bus_arb.*                       # sync_read 位次仲裁（纯逻辑，可主机测试）
│   ├── telem_pack.*                    # FeeTech 15 字节契约块打包（纯逻辑）
│   ├── critical.h                      # 极短临界区（发布寄存器镜像用）
│   ├── dbg.*                           # 调试口（宏可关、级别可调、防插帧）
│   ├── bus.*                           # 两个端口 + 协议自适应 + 粘滞 + 响应
│   ├── dxl2.*                          # Dynamixel 2.0 从站
│   ├── fee.*                           # 飞特 SCS/HLS 从站
│   ├── crc16.* / stuffing.*            # CRC-16 与 2.0 字节填充
│   ├── dev.*                           # 寄存器镜像、配置持久化、片内温度
│   ├── imu.* / imu_sim.*               # 传感器抽象 + 模拟器（IMU_USE_SPI=0）
│   ├── imu_spi.* / lsm6dsv16x.h        # 真 LSM6DSV16X 驱动（SPI0，IMU_USE_SPI=1）
│   ├── imu_math.*                      # 四元数/半精度工具
│   ├── app_header.*                    # 64 字节应用头（打包工具与 bootloader 共用）
│   ├── boot_crc32.*                    # 按位 CRC32（与 zlib/Python 一致）
│   ├── boot_flash.*                    # flash 抽象；主机测试用 256 KB RAM 后备
│   ├── boot_upgrade.*                  # 总线升级状态机（块 CRC/序号/整镜像 CRC）
│   ├── boot_regs.*                     # boot 模式寄存器空间（复用 dev_* API）
│   ├── boot_decide.*                   # 启动决策（纯函数，可主机测试）
│   ├── boot_ram.*                      # SRAM 握手字（NOINIT，跨软复位）
│   ├── boot_main.c                     # bootloader 主循环、跳转、boot 模式服务
│   ├── cfg_blob.*                      # 配置页 v2（设备配置 + 启动状态）
│   └── dev_cfg.c                       # 工厂默认值（应用与 bootloader 共用）
├── host/                              # 上位机（server.py + web/ + bus.py + package.py + upgrade.py）
├── host/tools/                        # C/Python 测试、boot_node_sim、servo_probe、sensor_probe、py.sh、run_c_tests.sh
├── docs/                              # 协议、Flash/boot、升级、降本路线文档
├── patches/                           # 飞特模块与 microduck 补丁
└── docs/refs/                          # 参考实现（rustypot 源码、XL330 控制表）
```

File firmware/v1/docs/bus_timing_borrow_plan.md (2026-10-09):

# 总线从站契约与实施计划（真舵机实测校正版）

> **状态：P0 与 P1 已实施并在真机上验证（2026-09-24）；真 `imu_to_dxl` PCBA 已回板，
> 与 15 颗真舵机共总线完成联调（2026-09-25）。**
> 本文分两部分：§1–§3 是 2026-09-23 用 `/dev/ttyACM1` 上的真舵机做的**只读**实测与据此
> 选定的方案（D1–D8）；§4/§4.1 是实施内容；**§4.6 记录真机联调中暴露并修掉的三个固件缺陷**；
> **§7 是实施后的真机验证结果**（实测数字，§7.6 起为真 PCBA + 真 LSM6DSV16X + 15 颗舵机）。
> P2 的剩余项（IDLE+DMA 收包、验收工具补齐）仍待做，见 §8。

**外部依据**（GitHub 上另一位复刻者的方案，本仓库不收录，仅引用）：

| 文档 | 大小 / sha256 前缀 | 内容 |
|---|---|---|
| `总线协议.md`（`imu_to_dxl` 总线协议 · 固件实现规格） | 14563 B / `72277360` | 从站契约：15 字节块、状态位、时序与排队规则、上电时序、主控判据、各指令应答表、寄存器区、验收清单 |
| `飞特适配架构.md`（官方运行时换飞特舵机 · 架构分析与适配方案） | 65387 B / `2080819c` | 主机侧：`RobotIo` 接缝、`FeetechIo`、rustypot 复用、增益/EEPROM/REBOOT/IMU 路线、台架验收 |

来源：`github.com/fanhao375/microduck-replica`。

**实测依据**（本仓库 + 真硬件）：

* `host/tools/servo_probe.py`（只读探针：PING / READ / SYNC_READ，绝不写）
* `software/hls_servo_debugger/`（HLS 浏览器调试台 + `hw_test.py`，依据厂商 `HLSCL.cpp` / `SCS.cpp`）
* 厂商手册 `飞特通讯协议说明.md`（仓库根 `docs/`）与 `HLS系列舵机内存表.html`（随硬件资料提供，
  未随仓库发布）
* 我方固件：`src/bus_arb.c` / `src/telem_pack.c` / `src/us_time.c` / `src/uart_port.c` /
  `src/bus.c` / `src/dev.c` / `src/fee.c` / `src/dxl2.c`

**标注约定**：【实测】= 真舵机/本机实测；【外部】= 对方文档；【读码】= 我方源码；【估算】= 推算。

---

## 0. 结论：选定的方案

| # | 决定 | 选择 | 主要依据 | 状态 |
|---|---|---|---|---|
| **D1** | 共享 `sync_read` 的块长与布局 | **FeeTech 地址 56 改成 15 字节"契约块"**：0–11 数据、12 = 采样计数、13 = 状态位、14 = 0；**诊断块（加速度等）留在 128 别名（20 字节，布局不变）**；DXL 视图（124，20 字节）不动 | 真舵机 56..70 就是 15 字节【实测】；改块长会把一次事务从 4.9 ms 推到 5.7 ms【估算 §2】 | ✅ 已实施（`src/telem_pack.c` + `dev.c`），真机验证 §7 |
| **D2** | sync_read 位次仲裁 | **按"每个前导 ID 占一个槽"推进**：槽长实测 ≈ 295 µs；**前导设备缺席也照样占一槽**；不要用"1 ms 总线静默判缺席" | 【实测】k=1/2/3 个缺席在前 → 首字节 0.828/1.121/1.408 ms，k=0 基线 0.526 ms，**每个前导 ID +0.294~0.302 ms**，线性；对方"静默 1 ms"会让我们晚一整槽撞包 | ✅ 已实施（`src/bus_arb.c`），真机验证 §7 |
| **D3** | 应答实时性 | **帧结束判定进 USART 中断；组帧后由 DMA 发送；遥测快照由主循环预发布** | 【实测】排在后面的舵机只等 ≈ 295 µs 就开口；主循环路径给不出这个上界 | ✅ 已实施（中断解析 + DMA0 CH3/CH6 + `critical.h` 发布） |
| **D4** | 自收自播（单总线回声） | **改成"TX 忙期间丢弃 + 2 字节时间保护"**，删掉原来的 `+2 ms` 窗口 | 【读码】`uart_port.c` 的整数除法让 21/31 字节应答一律产生 2 ms 静默；【实测】我们发完 210 µs 后 ≈85 µs 后面的设备就可能开口 | ✅ 已实施（`tx_busy` + **时间锚定的 `UART_ECHO_WINDOW_BYTES` = 3 字节时间**；真机上固定的"2 字节"会吃掉下一帧的 `FF FF`，见 §4.6.1） |
| **D5** | 应答 STATUS 字节 | **恒 `0x00`**；内部错误改记到厂商窗 `V_LAST_ERR`(179) | 【实测】真舵机正常读 STATUS 恒 0；飞特工具会把非 0 当舵机故障位；我们自己的补丁也曾把 `status != 0` 当整条事务失败 | ✅ 已实施（应用 + boot 模式） |
| **D6** | 身份寄存器 | 0/1 = **真实固件版本**；3/4 = **可辨认的自定义型号** `0x4D49`（'I','M'，**native 人格**；ft6 人格为 `0xF200`，见 `imu_to_dxl_protocol.md` §16） | 【实测】真舵机 0/1 = 3.46、3/4 = `0x1F0A`；`0x0C00` 会被 FD 当成某种 STS | ✅ 已实施，真机读到 `1.0 / 0x4D49`（native 人格） |
| **D7** | 校验和错误 | **静默丢弃**（保持现状） | 【实测】真舵机对坏校验帧完全不应答；我方 FeeTech 人格已一致（DXL 人格回 `ERR=0x20`，那是 DXL 的正确语义） | ✅ 已是行为，无改动 |
| **D8** | 主机侧缺席/故障策略 | **快速失败**：burst 以"总线安静"结束（**当时定 2 ms，2026-10-02 按实测放宽到 4 ms**；不是 30 ms 串口超时），缺席/故障的 ID 在一条错误里列出来；**不做"沿用上次值并返回 Ok"** | 【读码】`robotd` 已经在读失败时 `coast.sample(None)`（沿用上一份好样本并计 `consecutive_errors`），所以"喂假数据"既没必要也不安全；要修的只是那 30 ms 卡顿与中途放弃 | ✅ 已实施（`software/microduck_feetech/duck-control/src/bus.rs`，`cargo test -p duck-control` 通过） |
| **D9** | FeeTech `0x08` REBOOT | **节点实现**：不应答、`dev_request_reboot()`（应用与 bootloader 共用）；**主机补丁实现**：先写扭矩 0、发 `0x08`、**不等应答**立即返回 | 【实测】真机 fw 3.46：0x08 存在、不应答、**823 ms** 回来、EEPROM 设置全保留、RAM 增益回到 EEPROM（§1.7）——正好是 `RobotIo::reboot` 契约要的语义 | ✅ 固件已实施 + 单测；主机补丁见 `patches/README.md` |

| **D10** | Dynamixel `0x8A`（Fast Sync Read） | **节点实现聚合帧**：指令同 `0x82`；`LEN = 1 + N×(X+4)` 覆盖整包、每段 `ERR + ID + DATA + 累积 CRC`、**不填充**、第 0 台发 8 字节前缀；本机排第 k 位时**按前面 k 段的字节数**让位（`8 + k×(X+4)`），**不用 D2 的槽** | 【外部】ROBOTIS 手册 + 官方 32 字节示例，本机逐段 CRC 核过（`imu_to_dxl_protocol.md` §3.2.1）；【推算】一段只有 `(X+4)×10 µs`（X=12 → 160 µs），比 295 µs 的槽短，按槽让位必撞 | ✅ 已实施（`src/dxl2.c`、`src/bus.c`、`src/crc16.c`）；宿主逐字节测试 + 与 **rustypot 1.8 真解析器对拍**通过；真机三种位次全过（§7.8）；真 XL330 同总线未验证（§8） |

**被否掉的方案**（避免以后反复）：

* ~~保持 20 字节块、把主机读长改成 20~~：真舵机确实答应（【实测】20/21 字节读都 OK，56..75 是真实寄存器），
  但每个应答多 5 字节 ⇒ 每台 +50 µs，事务从 **4.9 ms 涨到约 5.7 ms**，逼近 6 ms 验收线（§2）；
  而且"读超出文档块长"在别的型号/固件上不保证（本机 fw 3.46 只是恰好支持）。
* ~~按对方原文用"1 ms 静默"判前导设备缺席~~：实测槽长 ≈ 295 µs，等 1 ms 会晚一整槽，直接撞包（§1.3）。
* ~~只做"ISR 置位、主循环发送"的过渡形态~~：主循环里一次 `stats_print`（1 Mbps 下 60 B ≈ 0.6 ms）
  就吃掉整个余量。已按 D3 的最终形态做（中断组帧 + DMA 发送）。
* ~~主机侧"缺席 → 沿用上次值 + 标 stale"~~：`robotd` 的 coast 已经做了这件事，见 D8。

---

## 1. 真机实测（2026-09-23，`/dev/ttyACM1`）

### 1.1 设备与身份

| 项 | 实测值 | 备注 |
|---|---|---|
| 适配器 / 设备 | `1a86:55d3 USB Single Serial`（cdc_acm）→ `/dev/ttyACM1`，权限 0666 | 宿主时间戳受 USB 限制（§1.6） |
| 波特率 | 1 Mbps（寄存器 6 = 0） | 与 `microduck` 的 1 Mbps 一致 |
| ID / 副 ID | **1** / 253（`0xFD`） | 副 ID 出厂是 0xFD（"未设置"），不是"禁止值" |
| 固件 / 端序 / 型号字 | **3.46**（`0x2E03`）/ **0 小端** / `0x1F0A`（10.31） | 对方 §9 要求"放真实版本号"，这就是对照 |
| 应答级别（8） | **1** | 与对方假设一致 |
| 运行模式（33） | **4** | 与对方 §2 的结论一致（不是 0） |
| 锁（55） | **1**（EPROM 写入掉电不保存） | 与我方 `dev.c` 的锁语义实现一致 |
| 最低输入电压 | **40 = 4.0 V**（母线实测 4.4 V） | 4.4 V 是**开发板 USB 供电能力不足**造成的，已知且临时；后续会提高到 7 V 以上，见 §1.7 |

### 1.2 地址 56 的块：12 / 15 / 20 / 21 字节都能读

| 请求长度 | 结果 | 数据（十六进制，56 起） |
|---|---|---|
| 12 | OK status=0 | `0100 0000 0000 2c 1d 00 00 00 01` |
| **15** | **OK status=0** | `0100 0000 0000 2c 1d 00 00 00 01 00 04 00` |
| 20 | OK status=0 | 追加 `00 00 f7 07 05`（= 寄存器 71..75） |
| 21 | OK status=0 | 追加 `3c`（= 寄存器 76） |

**解读**：56..70 的 15 字节是**文档化块**：
`pos(56) speed(58) load(60) volt(62) temp(63) 寄存器64 status(65) moving(66) 位置类(67-68) current(69)`；
再往后（71..76 实测 `0, 2039, 5, 60`）是别的寄存器，不是为外部设备预留的空间。
⇒ 想和舵机**共用同一个读长**，15 是唯一"足够、且对所有型号都成立"的选择（D1）。

### 1.3 位次与应答时序（每例 n = 21，取中位数）

| 用例 | 首字节（ms） | 相对基线 | 完整应答（ms） | 应答的 ID |
|---|---|---|---|---|
| `PING 1` | 0.339 | — | 0.416 | 1 |
| `READ 56/15` | 0.527 | — | 0.759 | 1 |
| `SYNC_READ [1]` | 0.526 | 基线 | 0.775 | [1] |
| `SYNC_READ [7,1]`（前 1 个缺席） | 0.828 | **+0.302** | 1.045 | [1] |
| `SYNC_READ [7,8,1]`（前 2 个缺席） | 1.121 | **+0.595**（+0.297/个） | 1.362 | [1] |
| `SYNC_READ [7,8,9,1]`（前 3 个缺席） | 1.408 | **+0.882**（+0.294/个） | 1.634 | [1] |
| `SYNC_READ [200,1]`（**运行时布局**：IMU 位缺席） | 0.829 | **+0.303** | 1.084 | [1] |
| `SYNC_READ [1,7]`（缺席在后） | 0.549 | +0.023 | 0.776 | [1] |
| `SYNC_READ [1]` 读 20 字节 | 0.606 | +0.080 | 0.894 | [1] |
| `SYNC_READ [7]`（只有缺席） | — | 超时 | — | [] |

**结论（D2 的依据）**：

1. 舵机**按 ID 列表里的位次**推迟应答，**每个前导 ID 占 ≈ 295 µs**，与"该设备在不在线"无关——
   线性度极好（0.302 / 0.297 / 0.294）。
2. 缺席在**后面**不影响（+0.023 ms）；只有前面的 ID 计入。
3. 295 µs ≈ 一个 21 字节应答的线上时间（210 µs）+ ≈85 µs 空隙/T_resp。
   ⇒ 排在后面的设备**只给我们 ≈ 295 µs**：从"指令帧最后一个停止位"到"我们第一字节"必须**紧**。
   这是 D3 硬指标的来源（比对方的"硬上限 100 µs"更贴近真实，但 100 µs 仍是应该守的目标）。
4. 因此**不能**用对方的"总线静默 1 ms 判缺席"：k=1 时应答窗口在 295 µs 就打开了。

### 1.4 坏校验帧

把 `READ 56/15` 最后一字节取反后发出：**完全不应答**（15 次全部超时）。与我方 FeeTech 人格一致（D7）。

### 1.5 寄存器底账（实测，0–90 中本次读到的字段）

| 地址 | 字段 | 实测 |
|---|---|---|
| 0/1 | 固件版本 | 3.46 |
| 2 | END 字节序 | 0（小端） |
| 3/4 | 型号/版本字 | `0x1F0A` |
| 5 / 6 / 7 | ID / 波特率 / 副 ID | 1 / 0（1 Mbps）/ 253 |
| 8 | 应答状态级别 | 1 |
| 9 | 最小角度限制 | 0 |
| 15 | 最低输入电压 | **40（4.0 V）** |
| 16 / 48 | 最大转矩 / 转矩限制 | 1000 / 1000 |
| 19 / 20 | 卸载条件 / LED 报警 | 4（BIT2 温度）/ 4 |
| 21 / 22 / 23 | **P / D / I（EEPROM）** | **32 / 40 / 0** |
| 26 / 27 | 死区 CW / CCW | 1 / 1 |
| 28 / 34 / 35 / 36 | 保护电流 / 保护转矩 / 保护时间 / 过载转矩 | 244 / 200 / 50 / 255 |
| 30 / 31 | 角度分辨率 / 中位偏移 OFS | 1 / 0 |
| 33 | 运行模式 | 4 |
| 37 / 38 / 39 | 电流环 P / I，速度环 P | 60 / 200 / 20 |
| 40 / 41 / 42 | 扭矩开关 / 加速度 / 目标位置 | 0 / 0 / 0 |
| 44 / 46 | 目标电流 / 目标速度 | 500 / 0 |
| 50 / 51 / 52 | **Kp / Kd / Ki（RAM）** | **32 / 40 / 0** |
| 55 | 锁 | 1 |
| 56 / 58 / 60 | 位置 / 速度 / 负载 | 1 / 0 / 0 |
| 62 / 63 | 电压（0.1 V）/ 温度 | 44（4.4 V）/ 29 |
| 64 / 65 / 66 | 寄存器 64 / 状态 / 移动标志 | 0 / 0 / 0 |
| 67 / 69 | 位置类字段 / 电流（6.5 mA） | 1 / 3~4（≈20–26 mA） |
| 73 / 75 / 76 | 寄存器 73–74 / 75 / 76 | 2039 / 5 / 60 |

**对我们的三条影响**：

1. **出厂 P = 32、D = 40**（对方文档说"手册没给"）。我们把 `microduck` 的 `gain = 200` 原样写进
   RAM 50 就是 **6.25 倍于出厂值** ⇒ 补丁的 `p_scale` 必须标定（若让 kp=200 落到出厂 32，
   `p_scale ≈ 0.16`）；对方 §3.3 的 `p = clamp(kp × p_scale)` 形状是对的。
2. **D ≠ 0（40）**：补丁"写 Kd = 0"是移植 XL330 的习惯；真机出厂带 D=40，是否清掉按阶跃响应定
   （属于 `patches/` 的整定清单，不是总线契约）。
3. **最低电压 4.0 V、母线 4.4 V**：4.4 V 是**开发板 USB 供电能力不足**所致（已知、临时），
   后续会提高到 7 V 以上；在那之前台架不做带载运动测试（真机 `robotd` 默认
   `battery_empty_shutdown` 6.6 V，不受影响）。

### 1.6 本次测量能力的边界（诚实说明）

* 所有时间都含 USB CDC 往返（`PING` 基线就 0.339 ms），**绝对 T_resp 测不到**；
  可信的是**同一条件下的中位数之差**（槽长 0.294–0.302 ms，21 次采样、线性一致）。
* 我们自己节点的 T_resp 要用示波器/逻辑分析仪量，或把我们的节点与这颗舵机接到同一条总线后
  用舵机的行为反推（它按槽长等我们）。**待查第 2 项。**

### 1.7 `0x08` REBOOT 实测（2026-09-24，用户确认舵机空载可重启）

对方《飞特适配架构》§3.4 说"飞特新固件有 REBOOT（0x08，约 800 ms，先关扭矩）"，
而仓库根 `docs/飞特通讯协议说明.md`（厂商手册）的指令表里**没有 0x08**（依据的是更旧的手册）。
用户允许重启（舵机输出轴没接任何负载），工具 `host/tools/servo_reboot_probe.py` 的实测：

| 项 | 实测 | 说明 |
|---|---|---|
| `0x08` 是否存在 | **存在**（HD-1910-C001，fw 3.46） | 我们的旧手册表缺这一条，需补 |
| 是否应答 | **不应答**（请求超时） | 与手册/对方说法一致 |
| 多久回来 | **823 ms**（PING 每 20 ms 轮询） | 与手册"约 800 ms"一致 |
| ID / 波特率 / 模式 / 锁 / OFS | **全部不变** | EEPROM 设置保留 |
| 扭矩 | 保持关（本来就是关） | 手册要求重启前先关扭矩 |
| RAM 增益 50/51 | 先把 Kp/Kd 写成 **99/88**，重启后回到 **32/40**（= EEPROM 21/22） | 证实"重启后 RAM 回 EEPROM"，正是 `RobotIo::reboot` 契约要求的 |

由此定下 **D9**（见 §0 表）：节点的 FeeTech 人格补上 `0x08`（不应答、走 `dev_request_reboot()`，
应用与 bootloader 共用），主机补丁的 `reboot()` 从"明确不支持"改成"先扭矩 0、发 0x08、不等应答"。

---

## 2. 用实测常数重算时间预算

槽长实测 ≈ 295 µs（= 21 字节应答 210 µs + ≈85 µs 空隙）。

| 方案 | 一次 16 设备事务（1 指令 + 我们 + 15 舵机） | 结论 |
|---|---|---|
| 共享长度 **15**（选定） | 240 + 210 + 15 × 295 ≈ **4.9 ms** | 6 ms 验收线内，余量 1.1 ms；占 20 ms tick 的 25% |
| 共享长度 20（否掉） | 240 + 260 + 15 × 345 ≈ **5.7 ms** | 只剩 0.3 ms 余量，任何抖动都越线 |

* 对方原估 3.6 ms，**低估约 35%**：它按"210 µs/设备"算，没算设备之间 ≈85 µs 空隙。
  ⇒ 我们的验收线用 **≈4.9 ms / p99 < 6 ms**。
* **我们自己的应答也必须在 295 µs 内起来**，否则第 1 颗舵机就在我们应答中间开口（D3）。
* **追加（2026-09-30，D10）：Dynamixel `0x8A` 的账【推算】** —— 16 台设备各读 12 字节时，聚合帧
  的 `LEN = 1 + 16 × 16 = 257`、整帧 264 字节 ≈ **2.6 ms**（1 Mbps、10 bit/字节），比上表 `0x82`
  的 4.9 ms 省约 2.3 ms：每台少一个 7 字节帧头与一次 ≈85 µs 转向，代价是每段多 2 字节 CRC。
  这条路径与原版 Dynamixel 路线绑定（FeeTech 总线没有 `0x8A`），不影响上面的 FeeTech 预算。

---

## 3. 风险清单（带实测支撑）

| 编号 | 风险 | 实测/读码依据 | 影响 | 处置 |
|---|---|---|---|---|
| **R1** | 我方应答晚于第一颗舵机 | 舵机只等 ≈295 µs【实测】；原实现是主循环组帧 + 阻塞发 | **整条 sync_read 错位，丢一个 tick 的全部传感器** | ✅ **已修**（D2 + D3）：中断组帧 + DMA 发送，位次仲裁；真机验证 §7 |
| **R2** | 帧后 2 ms 静默窗口吞指令 | 【读码】原 `uart_port.c` 整数除法 ⇒ 21/31 字节一律 2 ms | 流水式主机（升级工具实测 2.5 ms/事务）丢帧 | ✅ **已修**（D4）：`tx_busy` + 2 字节 |
| **R3** | 遥测快照非原子 | 【读码】原 `dev_read()` 每次调 `dev_refresh()`（3×20 B memcpy + `vendor_sync` + 1 Hz ADC/浮点），靠"全在主循环"侥幸 | 一旦 D3 把应答搬进中断 ⇒ 陀螺/四元数来自不同时刻 | ✅ **已修**（D3）：主循环发布 + 极短临界区，读不再刷新 |
| **R4** | 主循环长任务抖动 | `dbg` 行 ≈0.6 ms@1 Mbps、擦页 25 ms、未来 SPI IMU 驱动【读码/估算】 | 延迟应答的派发误差 | ◐ 已加 `loop_max` 高水位统计；实测最坏 5.2 ms 全部来自调试口补打统计行（生产构型两个 UART 分开，不存在共享，见 §8） |
| **R5** | 一颗设备缺席/故障 ⇒ 整条事务失败 | 【读码】原补丁：缺席等 30 ms；`ack.status != 0` 直接 `Err` | 一个 tick 卡 30 ms（> 20 ms 周期） | ✅ **已修**（D8）：总线安静结束 burst（2 ms → **4 ms**，2026-10-02）+ 故障不中断收集；`cargo test -p duck-control` **108 项**通过 |
| **R6** | 残帧粘连 | 【读码】原来只有 20 ms 整帧超时，无字节间隙判据 | 丢一帧 + `bad_sum++` | ✅ **已修**（P2-1）：帧中途间隙 > 500 µs 丢弃并计数 |
| **R7** | 台架供电 4.4 V | 【实测】最低输入电压 4.0 V | 带载欠压/堵转被误判为通信问题 | 台架不做带载运动（§6） |

---

## 4. 实施内容（P0/P1，2026-09-24 已完成）

> 下面每一节先保留当初的"要做什么"，末尾加 **实施结果**，逐条说明落地到了哪个文件、
> 与计划有何偏差。实测数据集中在 §7。

### P0-A · sync_read 位次仲裁（D2）

* **做什么**：`fee.c` / `dxl2.c` 的 `SYNC_READ` 分支不再立即出帧，改为返回"待发 + 位次状态"；
  新增应答调度器（`bus.c` 层或独立 `src/bus_arb.c`）：
  ```
  收到 sync_read 指令帧结束 → 记下自己的下标 k、读长、地址
  对 j = 0..k-1：
      等 (a) 一个完整的、ID 在列表里的应答帧结束（按长度/校验和判定），或
         (b) SLOT_US ≈ 300 µs 超时（缺席设备同样只占一槽）
      出现新的指令帧（FF FF …）→ 本次作废
      累计等待 > 25 ms → 放弃（不应答，计诊断）
  → 交给 P0-B 的发送路径（T_resp ≤ 100 µs 目标）
  ```
* **依据**：§1.3 的线性槽长；对方的"1 ms 静默"在这里是错的。
* **需要**：µs 级时基（DWT 周期计数或自由运行 TIMER；systick 只有 1 ms）。
* **风险**：等在前面时要保持接收；半双工单总线上只收不发是合法的。
* **验证**：把 `servo_probe.py` 的思路扩成"我们的节点 + 真舵机同总线"，
  两种布局都要过：200 在第 0 位（运行时）、不存在的 ID 排在 200 前面。

**实施结果**：`src/bus_arb.c`（纯逻辑，无硬件依赖）+ `bus.c` 的 `bus_emit()`。
`fee.c` / `dxl2.c` 只在 slave 结构里多记两个字段 `sync_named` / `sync_index`（在自己的
`SYNC_READ` 分支里填），不改 `*_slave_feed()` 的签名。**与计划的偏差**：
* 不做"观察前面应答帧结束"的嗅探——实测前导设备**缺席也占一槽**（§1.3），
  等应答帧结束与固定 300 µs 在同一个 `sync_read` 里是同一件事，固定槽更简单也更可测；
* 不做"25 ms 放弃"——槽数是有限的（k ≤ 250），等待天然有界；
* 取消等待的条件是"出现新的指令帧（本机 ID 或广播）"，由一个 3 字节小状态机判断
  （FeeTech 第 3 字节是 ID，DXL 第 3 字节是 `0xFD`、ID 在第 5 字节），见 `bus_arb_rx()`。
  在真机上用"前导 ID 缺席"的方式验证了线性槽长（§7）。

### P0-B · 硬实时应答路径 + 原子快照 + 回声窗口（D3 + D4）

* **做什么**：
  1. 帧结束判定放进 USART 中断（现在只把字节塞进环）；
  2. 组帧（≤ 31 字节）后用 **DMA 发送**（GD32F303 有 DMA，本工程目前完全没用），CPU 立即返回；
     发送完成中断里清标志/开回声门；
  3. 遥测快照：主循环发布 `telem_snapshot_t`（12 字节数据 + 计数 + 状态位 + 加速度 + 版本），
     中断侧只做定长拷贝；`dev_refresh()` 不再出现在读路径，ADC/浮点/`vendor_sync` 全部移出；
  4. 回声：`uart_port` 的回声门从"发送后 2 ms"改成"TX 忙期间 + 2 字节时间（≈20 µs）"，
     保留 `echoed` 计数用于确认窗口。
* **指标**：T_resp 目标 ≤ 100 µs、**硬上限 < 250 µs**（实测余量 ≈295 µs）。
* **风险**：DMA 与逐字节 RX 中断共存要小心（TX/RX 分通道）；ISR 里组帧只能用静态缓冲，
  不能再进 `dev_read` 的"每次刷新"路径；RX 环 256 B 与突发 315 B 的耦合（收紧回声门后
  15 颗舵机的应答会进环 ⇒ 主循环单次迭代必须 < 环一半 ≈1.28 ms）。
* **验证**：示波器/逻辑分析仪量 T_resp 直方图；P0-A 的同总线测试；连续 1000 次背靠背读 0 丢失。

**实施结果**：
* `uart_port.{h,c}` 不再有 RX 环形缓冲：中断收字节 → `on_byte(index, byte)` 回调 → `bus.c`
  里跑协议状态机；TX 改成 `uart_port_write_dma()`（USART0_TX = DMA0 CH3、USART1_TX = DMA0 CH6，
  取自 GD32F30x 用户手册图 10-4，并用真机验证），`DMA0_Channel3/6_IRQHandler` 在 `gd32f30x_it.c`；
* 每个端口一份应答缓冲 + 一份延迟缓冲（512 B each，RAM 因此 +1 KB）；
* 遥测发布：`dev_refresh()` 只在主循环调用（`main.c` 里"新样本或 50 ms"触发），
  用 `src/critical.h` 的 `irq_save/irq_restore` 包住几十字节的发布；`dev_read()` 不再刷新；
* 在 `uart_port_write()`（调试口）的字节循环里逐字节检查 `tx_busy`：开发板上调试口与总线
  共用 USART0，日志行必须在字节边界给协议帧让路——**这是真机跑冒烟时才暴露的**，
  最初只是"整行前检查一次"，一行 100 字节写到一半就会被协议帧插进来；
* 回声门最后落成**时间锚定窗口**而不是固定字节数：`uart_port_tx_complete()` 只设置
  `echo_until_us = us_now() + echo_window_us(baud)`（3 个字节时间，1 Mbps 下 ≈30 µs），
  `uart_port_isr()` 用 `tx_busy || (int32_t)(echo_until_us - us_now()) > 0` 丢弃自收字节。
  固定 2 字节在真 PCBA 上会吃掉下一帧帧头，见 §4.6.1；
* `main.c` 增加主循环迭代时长的**高水位统计**（`loop_max`），在统计行里打印；
* **偏差**：`dev_temp_celsius()` 仍保留在 `dev_refresh()` 里（1 Hz 限频 + 在临界区之外读），
  没有单独搬走。

### P1-A · FeeTech 视图改成 15 字节契约块（D1）

* **做什么**：
  * `src/board.h`：新增 `FEE_BLOCK_LEN 15` 与 12/13/14 三个偏移常量；
  * `src/dev.c` `dev_refresh()`：FeeTech 的 56..70 = `12 字节数据 + cnt + status + 0`；
    **128 的 20 字节诊断块与 DXL 124 的块保持原样**；
  * `ro_fee`：只读范围 56..75 改为 56..70（别名 128..147 不变）；
  * 文档：`README.md` §3/§4、`docs/dynamixel_slave.md` 的地址表；
  * 主机侧：`host/bus.py` 的 FeeTech 解码改为 56/15（0..11 + cnt/status），加速度读 128；
    `host/tools/bus_smoke.py` 在 FeeTech 模式改读 128/20；`host/tools/test_protocols.c`
    增加"56/15 且 byte14 == 0"的断言。
* **依据**：§1.2（15 是文档块）+ §2（长度 20 会把事务推到 5.7 ms）。
* **好处**：`patches/` 里主机 tick 的 `len=15` **一行不改**，就拿到了采样计数与状态位。
* **风险**：地址表改动牵动上位机与测试，必须一次改齐（有回归测试兜底）。

**实施结果**：`src/telem_pack.c`（纯函数 `telem_pack_fee15()`，主机测试逐字节断言）+
`dev.c` 的 `dev_refresh()`（56 打包契约块，128/124 仍是 20 字节诊断块）+ `ro_fee`
只读范围收到 56..70、并补上 0..1（固件版本）。主机侧：`bus.py` 新增
`FEE_BLOCK_*` 常量、`ImuBlock.decode(data, protocol)`、`Link.read_contract()` 与
`contract_addr`；`Link.telemetry_addr` 在飞特侧改为 **128**（诊断块），
`device_info()` 改读 0..5；`bus_smoke.py` 增加"56/15、byte14=0、计数递增、
与 128 的计数一致"四条断言。**偏差**：加速度没有搬到 56+15，而是保持在 128
（56 处 71..75 不参与契约、保持 0），这样 128 的布局与既有上位机完全兼容。

### P1-B · STATUS 恒 0 + 主机侧快速失败（D5 + D8）

* **做什么**：`fee.c` 的 `status_from_err()` 一律回 0，错误改记到厂商窗 `V_LAST_ERR`(179)；
  `software/microduck_feetech/duck-control/src/bus.rs`：`drain_replies()` 里 `ack.status != 0`
  记为该设备的故障、继续收其它设备的应答；`sync_read_blocks()` 用**总线安静**结束 burst
  （当时定 2 ms，**现在是 4 ms**；而不是等 30 ms 串口超时），最后把"故障的 ID + 状态"和
  "缺席的 ID"合并成一条错误返回。
* **不做**："沿用上次值并返回 Ok"——`robotd` 已经在读失败时 `coast.sample(None)`
  （见 `robotd/src/main.rs` 的 `consecutive_errors` 与 `COAST_TICKS`），喂假数据只会
  让安全层看不见一颗坏舵机。
* **验证**：`cargo test -p duck-control` **92 项通过**（原 89 + 3 个新用例：
  缺席快速返回并被点名、故障不打断整条 burst、乱序应答仍按请求顺序返回）；
  `git apply --check` 在干净 clone 上通过。

**实施结果**：固件侧 `fee.c` / `dev.c` + `boot_regs.c`（boot 模式同样恒 0），主机侧
`patches/microduck-feetech.patch` 重新生成（108,650 B，`patches/feetech.rs` 未改动）。

### P1-C · 身份寄存器（D6）

FeeTech 0/1 = 真实固件版本（`FW_VERSION_MAJOR/MINOR`，真机读到 `1.0`），
3/4 = 自定义型号 `0x4D49`（'I','M'，与厂商窗魔数一致；**native 人格**，ft6 人格为 `0xF200`）；
DXL 侧 1200 保持 XL330 仿真不动，且两种人格一致。
同步改了 `bus.py` 的 `device_info()`（原来飞特侧读 3..4 且把固件报成 `None`，现在读 0..5）。

### P2-1 · 字节间隙丢残帧（> 500 µs）— 已随 P0-B 一起做

`bus.c` 的 `bus_on_byte()`：帧解析进行中且字节间隙 > `BUS_GAP_US` 就 `*_slave_reset()`
（只丢帧状态，保留统计与暂存的 REG_WRITE），并计 `gaps`。**实测发现**：最初把"空闲间隔"
也算成 gap，一晚上能积到一万多次，纯属噪声，已改成只在帧中途计数。

### P2-2 · IDLE + DMA 收包（可选，省中断；1 Mbps 下现在 0 丢字节【实测】）

### P2-3 · 验收工具补齐

`bad_id = 0`、事务 p99、12 字节窗口最长连续相同 < 25 帧、采样计数每帧 +1~4、上电 50 ms 内可应答；
用 `servo_probe.py` 的槽长/长度用例做参考。

### P3 · 记录不做

改回 rustypot 运行时（继续当逐字节裁判）；换 MCU；广播 PING 静默（保持与真舵机一致，但要标注）。

### 4.6 真机联调发现并修复的三个固件缺陷（2026-09-25）

> 本节是三处**只有真硬件才会暴露**的缺陷：现象 → 根因 → 修复 → 实测证据。触发环境：真
> `imu_to_dxl` PCBA（GD32F303CC，12 MHz HXTAL，LSM6DSV16X 在 SPI0 PA4–PA7，INT1/INT2 =
> PB0/PB1），节点 ID 200，与 15 颗 FeeTech HD-1910-C001（型号 `0x1F0A`、fw 3.46、mode 4、
> 7.2 V：右腿 10–14、左腿 20–24、颈/头/嘴 30–34）共用 1 Mbps 半双工总线；PC 经
> `/dev/ttyACM1`，调试口/镜像为 `/dev/ttyUSB0`（USART0，PB6/PB7，`BUS_MIRROR_ENABLE=1`）。
>
> **这段是当时的台架构型记录**：设备名、开关值和下面所有实测数字都按原样保留。固件后来
> 把 `BUS_MIRROR_ENABLE` 默认改成 **0**（调试口只输出日志），并把升级窗收紧成只认电机总线；
> 因此再复现这些实验时要么显式 `-DBUS_MIRROR_ENABLE=1`，要么把 PC 接到电机总线上
> （`docs/upgrade.md` §1）。
> 固件构建开关 `IMU_USE_SPI`（`src/board.h`、`CMakeLists.txt`，默认 1）选真驱动
> `src/imu_spi.c` + `src/lsm6dsv16x.h`，0 则回到模拟器 `src/imu_sim.c`；`src/imu.c` 是门面，
> 拥有 10 ms 采样网格。

#### 4.6.1 `echo_skip` 吃掉下一帧帧头（`src/uart_port.c`）

* **现象**：每两次事务只成功一次。`frames` = 200 次请求里 100；`rx_bytes` = 1600 B = 200×8，
  即每个请求都到了 USART，但一半从未被组帧。2 ms 间隔下 50/100/50/100 ok/timeout；
  20 ms 间隔下 50/50（所以不是总线碰撞）；每个请求前加 2 个哑字节时 100/0。
* **根因**：`uart_port_tx_complete()` 在 DMA 发送完成时固定设置 `echo_skip = 2` 字节，
  假设半双工收发器会把我们自己的应答回灌。这块 PCBA 的收发器**不回灌**，于是这 2 字节
  跳过一直留着，把**下一个请求帧的 `FF FF` 吃掉**。
* **修复**：把"固定字节数"换成**时间锚定的窗口** `UART_ECHO_WINDOW_BYTES`
  （3 个字节时间，1 Mbps 下 ≈30 µs，按波特率算）：`uart_port_tx_complete()` 只设置
  `echo_until_us = us_now() + echo_window_us(p->baud)`，`uart_port_isr()` 用
  `tx_busy || (int32_t)(echo_until_us - us_now()) > 0` 丢弃自收字节（`src/uart_port.c`）。
  时间窗口不可能吃掉合法帧头——最早的合法流量约 85 µs 之后，主机下一条指令是毫秒级。
* **实测证据（修复后）**：400/400 次应答；节点侧 `rx=3200 frames=400 answered=400
  tx=8400 echo=0`。

#### 4.6.2 `us_now()` 每 35.8 s 回绕，所有期限失效（`src/us_time.c`）

* **现象**：节点在一次运行中途**静默**，但传感器仍报健康——
  `uart1 rx=1396097 echo=710906 frames=29758 answered=1747`，`frames`/`answered` 冻结，
  而 `echo` 以恰好等于接收速率的速度增长（每个字节都被当成回声丢弃），
  `loop_max=4259175904us`。
* **根因**：`us_now()` 返回 `DWT->CYCCNT / cycles_per_us`。CYCCNT 在 2^32 个周期
  （120 MHz 下 35.8 s）回绕，于是微秒值每 35.8 s 掉回 0，而不是按 2^32 µs 回绕；
  `(int32_t)(deadline - us_now()) > 0` 这类判据每次回绕后都会误判一次。
* **修复**：`us_time_tick()` 由 SysTick 处理函数每毫秒调用一次并重新锁存 CYCCNT
  （`src/gd32f30x_it.c` 的 `SysTick_Handler()`）；`us_now()` 返回
  `ms * 1000 + (CYCCNT - latch) / cycles_per_us`，亚毫秒部分钳到 999，于是它是真正的
  modulo-2^32 微秒计数器（回绕 71.6 min），且 `(ms, latch)` 这一对在短临界区内读取
  （`src/us_time.c`）。
* **实测证据（修复后）**：重 `sync_read` 流量下 `echo=0`；同一次运行的 `loop_max` 变成
  正常的 6 ms（台架构型下调试口与总线共用 USART0，这 6 ms 是调试口那条阻塞的统计行）。
* **连带解释**：`robotd` 此前"打开端口后第一次 `sync_read` 就缺 id 200"以及间歇的
  "4 次 stale 读"，根因都是这个时钟；时钟修好后 `robotd` **第一次**就绑上了总线。

#### 4.6.3 SFLP 重启发布未收敛姿态（`src/imu_spi.c`）

* **现象**：SFLP 重启后"融合重新收敛前四元数字节为零"的文档契约失效：`VCMD_RESET_SIM`
  之后四元数在 2.5 s 内从未归零（第一次非零在 2 ms）。
* **根因**：`imu_spi_restart()` 只把六个四元数字节清零一次，但芯片在 `SFLP_GAME_INIT`
  脉冲期间**继续输出格式良好的 SFLP 字**（实测 `sflp_words` 以约 115.5/s 持续增长、
  重启期间无停顿），下一次 `imu_spi_step()` 在 `dev_refresh()` 发布之前就把零覆盖了。
* **修复**：`src/imu_spi.c` 新增 **CONVERGE 状态**：重启后（以及初始化后）驱动丢弃 SFLP 字，
  发布零四元数字节并清 `TELEM_FLAG_SFLP_VALID`，持续 `LSM_SFLP_CONVERGE_MS` = 1500 ms
  （数据手册 0.8 s 校准 + 0.7 s 稳定，`src/lsm6dsv16x.h`），然后 flush FIFO 再恢复发布
  （`imu_spi_begin_converge()` / `imu_spi_end_converge()` / `imu_spi_step()`）。
* **实测证据**：两条 SFLP 重启冒烟检查现在通过——"VCMD_RESET_SIM zeroes the quaternion"
  在 **9–13 ms** 后归零；"SFLP 在重启后 **1.51–1.52 s** 恢复非零（< 2.5 s）"。
* **附带：FIFO tag 编码（排查时踩的坑）**。`TAG_SENSOR[4:0]` 是 tag 字节的 bit 7:3，
  `TAG_CNT` 在 bit 2:1，所以 game rotation vector 的原始字节是 `0x13 << 3` = `0x98`
  （实际读到 `0x98/0x9A/0x9C/0x9E`）。拿字节直接和 `0x13` 比较**什么也匹配不到**——
  这浪费了一轮调试，现在由 `src/lsm6dsv16x.h` 的 `LSM_TAG_SENSOR()` 和
  `host/tools/test_protocols.c` 的 `test_lsm_fifo_tag()` 钉住。

---

## 5. 验收与台架

| 台架 | 做什么 | 通过标准 | 状态 |
|---|---|---|---|
| **B0** | §1 的只读复现 | `servo_probe.py` 输出与 §1/附录 A 一致 | ✅ 已完成（§1） |
| **B1** | **我们的节点 + 这颗真舵机同一条总线**（两个适配器的收发接到同一条半双工线，共地） | 200 在第 0 位：我们 295 µs 内开口、舵机紧随、无重叠；200 在中间/末尾：按槽让位不撞包 | ◐ 真 PCBA 已与 **15 颗**舵机同总线（ID 200 + 10–14/20–24/30–34，共 16 个 ID 的一次 `sync_read`）**150/150 完整**（§7.7）；运行时 200 固定在第 0 位，所以"中间/末尾让位"仍只用**缺席前导设备**验证（§7.3） |
| **B2** | 事务耗时（1 节点 + 1 舵机 + 14 个假从站模拟） | ≈4.9 ms；p99 < 6 ms | ✅ 真总线实测：16 ID、地址 56、长度 15 的 `sync_read` 主机**往返**中位 **8.74 ms** / p95 8.86 ms / max 8.95 ms（含 USB CDC，不是纯线上时间；§7.7） |
| **B3** | T_resp 直方图（逻辑分析仪/示波器） | 典型 ≤ 100 µs，**最大 < 250 µs** | ⛔ 未做（需要仪器） |
| **B4** | 连续背靠背读 | 0 次无应答、`rx_dropped = 0` | ✅ 已完成：开发板冒烟 2555 次轮询、0 超时 0 坏帧、`dropped=0`（§7.2）；真总线背靠背 200/200（§7.7），真驱动冒烟 Dynamixel 3851 / FeeTech 5372 次轮询、0 超时 0 坏帧（§7.6） |
| **B5** | 上电应答 / 坏校验静默 / 广播 PING | 上电 ≤ 50 ms；坏校验静默（实测一致）；广播 PING 行为记录在案 | ◐ 坏校验静默已实测（§1.4 真舵机 + 我方一致）；上电时间与广播 PING 未测 |

---

## 6. 待查（需要第二台设备或仪器）

1. ~~前导设备缺席时的槽长~~ **已实测**（线性 ≈295 µs/个，§1.3）。**前导设备真的应答时**
   槽长是否相同仍未测（需要第二颗舵机，或把我们的节点接上互测）——两种模型
   （"等应答帧结束" vs "固定 300 µs"）在同一个 `sync_read` 下等价，所以只影响极端情况。
2. **我们自己节点的绝对 T_resp 仍未测**（USB 时间戳分辨率不够，要示波器/逻辑分析仪，
   或把 P0-B 的 DMA 启动/完成接到空闲 GPIO）。间接证据：延迟槽实测 ≈330 µs/槽，
   与设计的 300 µs 只差主循环派发抖动，说明延迟路径的时序是准的。
3. 真机（15 颗 HD-1910）批量槽长是否与单颗一致（负载、线长、方向电路换向时间）。
4. ~~`0x08` REBOOT 是否存在~~ **已实测存在**（不应答、823 ms 回来、设置保留、RAM 增益回 EEPROM），
   见 §1.7；节点与主机补丁都已按此实现（D9）。**仍未测**：`0x09`（参数备份）与
   `0x0A`/`0x0B` 在真机上的行为（前者会写 EEPROM，未获授权；后两者本节点也不需要）。
5. 广播 PING 在多设备下的实际后果（我们选择应答，与厂商参考库一致）。
6. 我方自动方向电路（`Q1 + R28/R29/C22`）的实际换向延迟 ⇒ 定 D4 的保护字节数（现在是 2 字节）。
7. ~~把母线提到舵机额定电压再做带载测试~~ 供电已知：**4.4 V 是开发板 USB 供电能力不足**，
   后续提高到 7 V 以上；届时再做带载测试（当前不做）。

---

## 7. 实施后的验证（2026-09-24；真 PCBA 2026-09-25）

> §7.1–§7.5 是 2026-09-24 在 GD32F303CC 开发板上的一轮；§7.6–§7.7 是真 PCBA +
> 真 LSM6DSV16X + 15 颗真舵机的一轮。

### 7.1 主机测试（无硬件）

`./build.sh test` 全绿：

| 套件 | 结果 |
|---|---|
| CRC-16 vs rustypot/ROBOTIS、CRC-32 vs `zlib.crc32` | 全部向量一致 |
| 协议从站（含新增用例） | 通过。新增：`telem_pack` 契约块布局、`sync_index`（fee/dxl 的 k=0/中/不在列表）、`bus_arb`（槽计时/一次跨多槽/四种取消条件）、间隙复位（fee/dxl） |
| bootloader（`test_boot.c`） | **9509 断言 / 0 失败** |
| 升级工具 pty 端到端（`test_upgrade.py`） | **173 断言 / 0 失败** |
| 包格式自测、`bus.py` 编解码、网页服务器 | 通过 |
| `cargo test -p duck-control`（补丁） | **92 项通过**（原 89 + 3） |

### 7.2 真机（GD32F303CC 开发板 + `/dev/ttyUSB0`，1 Mbps）

`flash-pair a`（整片擦除 + bootloader + slot A v1.2.0）后 `BUS_PORT=/dev/ttyUSB0 ./build.sh smoke`：

| 项目 | Dynamixel 2.0 | 飞特 SCS |
|---|---|---|
| 持续轮询 | 361 Hz，中位 2.71 ms、p95 2.84 ms | 391 Hz，中位 2.52 ms、p95 2.57 ms |
| 超时 / 坏帧 | 0 / 0 | 0 / 0 |
| 身份 | 型号 1200、固件 `0x10` | **固件 `1.0`、型号 `0x4D49`（'I','M'）（native 人格；ft6 为 `6.0 / 0xF200`）** |
| 字节填充 | 40 个被填充的帧全部正确解出 | — |
| 契约块 / 诊断块 | 124 的 20 字节块 + 12 字节控制块 | **56/15（byte14=0、计数递增）** + 128/20，两者计数一致 |
| **FeeTech `0x08` REBOOT**（本轮新增） | — | **不应答**；约 **160 ms** 后自己重启（重启前后用 DXL 寄存器 120 的 uptime 验证：从 ~50 s 掉到 241 ms）；重启后型号/固件/寄存器都不变 |
| 设备语义 | — | ACK 级别 0 → 写静默、读仍应答；锁着写 RAM 生效 |

> **主机侧测量注意（我第一次踩的坑）**：协议的 100 ms 粘滞窗口是**按端口**算的。
> 如果先做了一次 DXL 事务、紧接着（<100 ms）发 FeeTech 的 `0x08`，节点会把它当噪声忽略，
> 表现是"0x08 没反应也不重启"。测量 `0x08` 之前先发一帧同协议请求（或等 >100 ms），
> 或者干脆用同一个协议连接做完全部操作。

**关于偶发的 1 次超时（诚实记录）**：四次冒烟里有一次出现 `timeouts=1 / 2538 polls`
（其余三次 0）。随后做了一次 30 s 定向复测：**12157 次轮询、0 超时 0 坏帧 0 多余字节**，
而固件自己的计数器是 `frames=22445 answered=22445 dropped=0 err=0 echo=0`、
`bus held=45 lost=0 gaps=0`（2026-09-30 起这一行末尾多了 `ignored=`，同一行还打印被拒绝/被作废的帧数）—— **每一条帧都答了、没有一次发送被拒**，
所以那次超时出在主机/USB（CH340 + Python 调度）一侧，不是节点的应答路径。
`loop_max` 在两次读数里都是 ~5.2 ms，来源见 §8。

### 7.3 位次仲裁的真机实测（运行时不走的那条路）

主机直接发"前导 ID 全是缺席设备"的 `sync_read`，量一次往返（每例 15 次取中位）：

| ID 列表 | 往返 | 相对基线 |
|---|---|---|
| `[200]` | 2.396 ms | 基线 |
| `[7, 200]` | 2.735 ms | **+339 µs** |
| `[7, 8, 200]` | 3.072 ms | **+676 µs** |
| `[7, 8, 9, 200]` | 3.397 ms | **+1001 µs** |

* 线性，≈330 µs/槽（`BUS_SLOT_US = 300` + 主循环派发抖动），与真舵机的 295 µs 同量级；
* 固件统计里 `bus held` 的增量与主机发出的 60 次 k>0 事务**完全对上**，说明延迟缓冲这条
  路径真的被走到了、而且每条都发出去了；
* 绝对值仍含 CH340 的 USB 往返（≈2.4 ms），所以这是**相对**测量；绝对 T_resp 见 §8。

### 7.4 这一轮真机暴露并修掉的问题

1. **主机解码把 12 字节控制读当成"契约块太短"**：`ImuBlock.decode` 一开始对"飞特 + 长度 < 20"
   就走契约块分支，于是 `README` 里那条 128/12 的控制块读全被判坏帧（84 个）。
   改成只在**长度恰好 15** 时走契约块。这是主机侧 bug，但只有真机跑冒烟才会暴露。
2. **调试口一行日志写到一半会被协议帧插进来**：`uart_port_write()` 原来只在整行开始前检查
   `tx_busy`；现在改成在字节循环里逐字节检查，协议帧优先（日志行被截断而不是总线被破坏）。
3. **`gaps` 统计把空闲间隔也算进去**：一晚上积到 10360 次，毫无诊断价值；
   改成只在"帧解析进行中"且间隙 > 500 µs 时计数。
4. mock 层面的一个小错：飞特 `device_info()` 原来从 3..4 读型号（正确）却把固件报成 `None`；
   现在读 0..5，同时给出固件版本，冒烟测试的输出才和文档对得上。

### 7.5 资源占用（Release `-Os`）

| 目标 | 改造前（P0/P1 之前） | 改造后（P0/P1，2026-09-24） | 真机驱动（2026-09-25，`IMU_USE_SPI=1`） |
|---|---|---|---|
| 应用（开发镜像，254 KB） | 24.3 KB flash / 6.9 KB RAM | 26.1 KB / 8.0 KB | **24036 B / 254 KB；RAM 8288 B（16.95%，按 48896 B RAM 区算）** |
| slot 镜像（96 KB） | 25.0 KB (26%) | 26.7 KB (28%) | **24600 B / 96 KB (25.0%)** |
| bootloader（32 KB） | 17.1 KB (52%) | 18.7 KB (58%) | **18764 B (57.3%)** |

增量来自：DMA 应答（每端口 2 × 512 B 缓冲）、µs 时基、位次状态机、契约块打包、
真 LSM6DSV16X 驱动（SPI0 + CONVERGE 状态），以及 boot 模式同样带上这套协议行为。

### 7.6 真 PCBA + 真 LSM6DSV16X（2026-09-25）

`./build.sh` 构建（`IMU_USE_SPI=1`）后 `flash-pair a` 烧 bootloader + slot A，节点经
`/dev/ttyACM1` 上真总线（ID 200），调试口/镜像 `/dev/ttyUSB0`（1 Mbps）：
`host/tools/bus_smoke.py` 真传感器路径全过、`host/tools/sensor_probe.py` 只读表征全过。

| 项目 | 实测值 | 出处 |
|---|---|---|
| `WHO_AM_I` | **0x70** | `src/lsm6dsv16x.h`、串口 banner |
| SPI0 | **mode 0，7.5 MHz**（`SPI_PSC_16`，APB2 = 120 MHz） | `src/imu_spi.c` |
| 陀螺 / 加速度 / SFLP | ±500 dps @ 120 Hz 高性能 / ±4 g @ 120 Hz / game rotation vector @ 120 Hz | `src/lsm6dsv16x.h` |
| FIFO | continuous 模式，**只装 SFLP 字**，水位 12 字 | `src/imu_spi.c` |
| 静止加速度模长 | **996–997 mg**（探针 300 样本均值 997.4 mg） | `.test-out/sensor_probe.json` |
| 四元数范数 | **1.0000**（探针 300/300，min=max=1.0） | 同上 |
| 四元数重力 vs 加速度方向夹角 | **0.05–0.12°**（探针 mean 0.058°，max 0.115°） | 同上 |
| 陀螺零偏（原始计数，静止） | x=−55.7、y=+9.2、z=+41.8 counts → **x=−0.97 / y=+0.16 / z=+0.73 dps** | 同上 |
| 陀螺每轴噪声 std | **0.017–0.031 dps**（x 0.029 / y 0.030 / z 0.017） | 同上 |
| `gyro_bias` 厂商窗补偿值 | **(+56, −9, −42) raw counts**（固件是**加**上去的，`src/imu_spi.c`） | 同上 |
| 持续轮询（真驱动冒烟） | Dynamixel **1260 Hz / 3851 次轮询**、时延中位 0.75 ms；FeeTech **1789 Hz / 5372 次轮询**、中位 0.52 ms；**两者 0 超时 / 0 坏帧** | `smoke` 输出 |
| 两条 SFLP 重启检查 | `VCMD_RESET_SIM` 后 **9–13 ms** 四元数归零；**1.51–1.52 s** 后恢复非零（< 2.5 s） | `bus_smoke.py` |
| FIFO tag 回归 | `test_protocols.c` 的 `test_lsm_fifo_tag()`：`0x98/0x9A/0x9C/0x9E → LSM_TAG_SFLP_GAME`，且 `LSM_TAG_SENSOR(0x13) != LSM_TAG_SFLP_GAME` | `host/tools/test_protocols.c` |
| 主机测试 | `bash host/tools/run_c_tests.sh` 与 `./build.sh test` 全过 | — |

`bus_smoke.py` 现在是**传感器感知**的：它读 `TELEM_FLAG_SIMULATED`，对 `IMU_USE_SPI=0`
的构建保留原来的 7 种模拟模式检查；真传感器路径则检查状态位、四元数范数、加速度模长、
四元数重力 vs 加速度夹角、陀螺噪声与 SFLP 重启（检查名见文件内
`run_real_sensor()` / `run_real_restart()`）。`host/tools/sensor_probe.py` 是新增的只读表征探针。

> 注：当时台面上留下的 `.test-out/sensor_probe.json` 与 `.test-out/smoke_final.log` 是
> **CONVERGE 修复之前**的产物（`.test-out/` 是台架输出目录，不在仓库里）——它们的两条 SFLP
> 重启检查仍是 FAIL。上表的静止数字与它们一致，而重启数字（9–13 ms / 1.51–1.52 s）来自修复
> 后重跑的 `bus_smoke.py`。

### 7.7 与 15 颗真舵机共总线（2026-09-25）

主机在 `/dev/ttyACM1` 上直接发"ID 200 + 15 颗舵机"的一次 `sync_read`（地址 56、长度 15）：

| 场景 | 结果 |
|---|---|
| 16 ID，扭矩全关 | **150/150 完整** |
| 16 ID，15 颗全部上扭矩 | **150/150 完整** |
| 背靠背连续突发 | **200/200 完整** |
| 主机往返 | 中位 **8.74 ms** / p95 **8.86 ms** / max **8.95 ms**（含 USB CDC） |
| 节点侧 | 每秒约 **47/50** 次读被应答，`echo=0 dropped=0 err=0` |

**这条已在 2026-10-02 修掉**（原本记为主机侧遗留，不是固件/接线）：当时的现象是，把同样的
16 ID `sync_read` 交给 `robotd` 跑策略时，约 17.5 s 的使能运行里报了 **97 次** `bus read
failed ... sync_read: id(s) ... missing`（`/tmp/robotd7.log`；整个进程 98 条），缺失集合总是
**回复到达顺序的尾部**（`200`，然后 `23,24,30,31,32,33`，再 `24,30,31,32,33,34`）——是一段突发
提前结束，不是设备掉线。判断和处置都落在主机侧的突发处理（`sync_read_blocks()` +
`BURST_IDLE`/`pump()`）：

* **每笔事务多付一次 `tcdrain`**：`serialport` 的 `flush()` 实测固定 **~12 ms**（8/9/24/56 字节、
  有应答与无应答都一样），每 tick 两笔 → 控制环上限 ~41 Hz、实测 **36.3 Hz**、`missed` 占 48%。
  `flush()` 已从 `Transport` trait、`SerialPort` 包装与 5 个调用点删除。
* **`BURST_IDLE` 2 ms → 4 ms**：实测 13.5 万个相邻应答间隔 median 0.27 / p99 0.57 / **max 1.94 ms**，
  整串 ~4.9 ms 到齐；2 ms 只剩 3% 余量，按 1 ms 重放同一批时间线会立刻掉读 26/9000 tick。

改完同一块板子上是 **50.0 Hz / missed 0**。**残留**的孤立掉读（每 5 分钟窗口 0–3 次，≈1/15000
tick）**不是**尾巴型截断：2026-10-02 的 journal 里每一条都是 `id(s) … missing`（没有一条是
`faulted status`），缺失集合是**散的**（例如 `200,22`、`31,34`、`23,31`、`33,11`），而尾巴型截断
只会砍掉到达顺序的**一段后缀**——`200` 是第 0 槽、`22` 是第 3 槽，不可能是"最后才该到"的。
所以机制在驱动/舵机一侧，与这个判据无关，也没有再动它。本节与
`docs/imu_to_dxl_protocol.md` §12 第 8 项记录的是同一次测量。

（要看代码就引**本仓库**的 `software/microduck_feetech/duck-control/src/bus.rs` 的
`sync_read_blocks()`、`BURST_IDLE`、`pump()`——**不要**再引 `patches/microduck-feetech.patch`
的行号：那份补丁是移植当时的快照，行号在换基线时就全失效了。）

---

### 7.8 Fast Sync Read（`0x8A`）真机验证，以及由此揪出的中断延迟缺陷（2026-09-30）

节点（slot 镜像，`BUS_MIRROR_ENABLE=0`）挂在 `/dev/ttyACM0` 的电机总线上，与 15 颗 FeeTech 舵机
共线；主机用 `host/tools/fast_sync_read_check.py` 走 DXL 帧（舵机对 `FF FF FD` 开头的帧不响应）。
本轮刷机走的是 **A/B 升级**（`host/upgrade.py upgrade`，1606 块、0 重传、CRC 一致），全程没有芯片擦除。

**19 项全过【实测】**，其中三种位次都验了：

| 场景 | 结果 |
|---|---|
| 本节点在第 0 位（microduck 的 tick 读，`[200] + 15 关节`） | 应答 24 字节：`FE`、`LEN = 257`、`ERR = 0`、`ID = 200`、累积 CRC 正确；补上 15 段合成舵机段后整包 264 字节，`host/bus.py` 的参考解析器（照 rustypot 1.8 抄写）逐段校验通过，第 0 段就是本节点的 12 字节遥测（**不填充**：数据里带 `FF FF FD` 也原样发出） |
| 本节点在第 1 位（`[10, 200, 11]`，主机扮演 0 号设备发前缀+块） | 收满 24 字节后立刻发自己那 16 字节块（无前缀、无 error），补上第 2 段后整包 3 段解析通过 |
| 未被点名 / 前缀不对 | 静默（负例：只发块不发前缀，节点拒绝——`ignored` 计数 +1） |
| `0x8A` 与 `0x82` 同一采样 | 状态位一致、采样计数一致，计数未动时**字节完全相同** |
| 20 次背靠背读 | 0 丢失 |

**由此揪出的缺陷（重要，与 `0x8A` 无关的固件 bug）**：中间位置一开始**必失败**——节点收到
指令后从来不回应答，`ignored` 计数不变、`gaps` 也不变。用调试口逐位计数定位后确认：**USART1
的接收中断里解析完一整帧所需的时间超过了 1 Mbps 下一个字节的 10 µs，紧跟其后的字节被
USART 的单字节接收寄存器覆盖丢掉**（`rx_bytes` 比主机写入的字节数少 1 就是直接证据；
`rx_errors` 一直是 0，因为 ORERR 已被字节循环里那次读 DATA 清掉了——这也是一个统计盲点）。

* 根因是 **按位实现的 CRC-16**：`crc16_dxl(f, total-2)` 对 15..28 字节的指令帧要
  ≈1300..2400 个循环迭代，在 120 MHz 上约 **11..20 µs**，单这一项就超了一个字节时间。
* 处置：`src/crc16.c` 改成 **256 项查表**（多 512 B flash），`crc16_dxl_update` 降到约 5 个周期
  一次；所有向量（`host/tools/test_crc16.c` 的 rustypot/ROBOTIS 向量、协议测试、与真 rustypot
  的对拍）不变。改完 `rx` 增量与主机写入字节数**逐字节相符**，中间位置随即全过。
* 这条对整条总线都有意义：**任何一台"紧跟指令帧发言"的设备都会被吃掉首字节**。原来没暴露，
  是因为运行时把本节点放在第 0 位（它自己就是第一个发言的），而 §7.3 的延迟路径测量里前导
  ID 全是缺席设备（总线安静）。`0x8A` 是第一条要求"别人先说话、我们后说话"的指令。
* 顺带把 `dxl_slave_reset()` 的语义收紧了：`0x8A` 的聚合帧在**第一个字节到达之前**的间隔
  不再作废应答（前导设备允许有自己的 `return_delay_time`，出厂值 250 ⇒ 500 µs > `BUS_GAP_US`），
  但**流一旦开始**再断掉仍然作废——否则一段属于"不存在的包"的块会晚到地插入别人的事务。
  两条都有宿主测试钉住（`test_protocols.c`）。

资源占用（Release，`IMU_USE_SPI=1`，`arm-none-eabi-size`）：应用镜像 **25528 + 124 B / 254 KB**、
`RAM 8724 + 188 B (18.2%)`；slot 镜像 26028 + 188 B（26.7%）；bootloader **20200 + 116 B (62.1%)**
——比 §7.5 那一轮各多约 0.5 KB flash，全部是 CRC 表（512 B）。

---

## 8. 仍未做的（P2 剩余 + 真机仪器项）

| 项 | 为什么还没做 |
|---|---|
| `sync_read` 与**真舵机共总线**的端到端验证（计划里的 B1/B2） | **真 PCBA 已与 15 颗舵机同总线**：16 ID 的一次 `sync_read` 直连 150/150（扭矩开/关）、背靠背 200/200（§7.7）。仍缺：把 200 放在 ID 列表**中间/末尾**时"按槽让位不撞包"的直接验证（运行时 200 固定第 0 位，只有调试工具会走延迟路径；目前仍靠缺席前导设备 §7.3 间接验证） |
| 用示波器/逻辑分析仪量**绝对 T_resp**（计划里的 B3） | 宿主 USB 时间戳只到 ~0.3 ms，测不出"指令帧结束 → 我方向首字节"这段几十 µs；可以把 DMA 启动/完成接到空闲 GPIO 再用示波器看 |
| `0x8A` 与**真 Dynamixel 舵机共总线**的完整 16 设备读（D10） | 需要至少一颗 XL330（fw v46+）：本 bench 的 15 颗是 FeeTech HD-1910，所以 §7.8 验的是**本节点自己那一段**（三种位次、负例、背靠背 20 次全过）。真舵机是否照手册接在我们发的 8 字节前缀后面、它的 `return_delay_time` 是多少，都要有 XL330 才能测——而它直接决定"聚合帧是否会被 >500 µs 的间隔打断"（`imu_to_dxl_protocol.md` §15.5 第 11 项） |
| 主机侧突发截断 —— **已修（2026-10-02）** | 曾经：`robotd` 在约 17.5 s 里报 97 次 `id(s) ... missing`，缺失集合总是到达顺序的尾部。处置：删掉每笔事务的 `tcdrain`（固定 ~12 ms，36.3 → **50.0 Hz**）+ `BURST_IDLE` 2 → **4 ms**。残留的孤立掉读（0–3 次/5 分钟）是散点、不是后缀，机制在驱动/舵机一侧，见 §7.7 |
| IDLE + DMA 收包（P2-2） | 现在逐字节中断在 1 Mbps 下 0 丢字节（`rx_dropped=0`），只是 CPU 占用问题；**真 SPI IMU 驱动（`IMU_USE_SPI=1`）已加入**，实测仍 0 丢字节，所以这条保持"可选优化" |
| 验收工具补齐（P2-3：`bad_id=0`、事务 p99、25 帧冻结距离、上电 50 ms） | 需要与"多设备总线"一起做才有意义；单设备下 p99 已经被 USB 往返支配 |
| 生产构型（`BUS_MIRROR_ENABLE=0`）下的主循环抖动复测 | 本次 `loop_max` 到过 5.2 ms，全部来自调试口在总线安静 20 ms 后补打的统计行（5 行 ≈ 500 B @1 Mbps）。生产构型下调试口与总线是**两个** UART，运行时的应答（k=0）在中断里走 DMA，完全不受影响；只有**延迟应答的派发**（k>0，仅调试工具会触发）仍由主循环推进，可能被控制台输出推迟。要根治就把控制台也改成 DMA 发送，或生产镜像里把 `DBG_LEVEL` 降到 1 |

---

## 附录 A · 数字出处

| 数字 | 值 | 出处 |
|---|---|---|
| 字节时间 | 10 µs @ 1 Mbps | 【外部】 |
| 16 ID 指令帧 | 240 µs | 【外部】【读码】 |
| 单应答帧（15 字节块） | 210 µs | 【外部】【读码】 |
| **每前导 ID 的槽长** | **≈295 µs（0.294–0.302，n=21×3）** | **【实测】§1.3** |
| 事务总时长（共享长度 15 / 20） | **≈4.9 ms** / ≈5.7 ms | 【估算】用实测槽长 |
| 对方原估事务时长 | 3.6 ms（低估 ≈35%） | 【外部】 |
| 我们的应答窗口（后面的舵机等我们） | **≈295 µs** | 【实测】 |
| T_resp 目标 / 硬上限 | ≤ 100 µs / **< 250 µs** | 【外部】+【实测】 |
| 真舵机 56..70 块 | 15 字节（20/21 也读得到，71..76 是别的寄存器） | 【实测】§1.2 |
| 坏校验帧 | 不应答 | 【实测】§1.4 |
| 出厂 P / D / I（21/22/23）与 RAM Kp/Kd/Ki（50/51/52） | 32 / 40 / 0 | 【实测】§1.5 |
| 最低输入电压 / 实测母线 | 4.0 V / 4.4 V | 【实测】§1.5 |
| 我方自收自播窗口 | 发送期间 + **3 个字节时间**（`UART_ECHO_WINDOW_BYTES`，1 Mbps 下 ≈30 µs，按波特率算） | 【读码】`uart_port.c`；固定的 2 字节在真 PCBA 上会吃掉下一帧帧头，见 §4.6.1 |
| RX 缓冲 | 无（中断直接喂协议状态机） | 【读码】`uart_port.c`（旧的 256 B 环已删） |
| 主机 burst 结束判据 | **4 ms 总线安静**（`BURST_IDLE`；2026-10-02 由 2 ms 放宽，补丁快照里仍是 2 ms），不再是 30 ms 串口超时 | 【读码】`software/microduck_feetech/duck-control/src/bus.rs` |
| 擦页停顿 | ≈25 ms/页 | 【实测】 |
| **固件侧位次槽实测**（前导 ID 全缺席） | **+339 / +676 / +1001 µs（k=1/2/3）** | **【实测】§7.3** |
| **延迟缓冲命中** | 60 条 k>0 事务 ↔ `bus held` 60 | **【实测】§7.3** |
| 改造后资源占用 | app 26.1 KB / slot 26.7 KB / boot 18.7 KB | 【实测】§7.5 |
| **真机驱动资源占用**（`IMU_USE_SPI=1`） | **slot 24600 B (25.0%)、开发镜像 24036 B、boot 18764 B (57.3%)、RAM 8288 B (16.95%)** | **【实测】§7.5（`arm-none-eabi-size`）** |
| 真 LSM6DSV16X 静止四元数重力 vs 加速度 | **0.05–0.12°**（mean 0.058 / max 0.115，n=300） | **【实测】§7.6** |
| 真 LSM6DSV16X 陀螺零偏 / 噪声 std | **(+56, −9, −42) counts ≈ (−0.97, +0.16, +0.73) dps / 0.017–0.031 dps** | **【实测】§7.6** |
| 16 ID（200 + 15 舵机）`sync_read` 直连 | **150/150（扭矩关）、150/150（扭矩开）、200/200 背靠背；往返中位 8.74 / p95 8.86 / max 8.95 ms** | **【实测】§7.7** |
| 真舵机 `0x08` | 存在、不应答、**823 ms** 回来 | 【实测】§1.7 |
| 本节点 `0x08` | 不应答、约 **160 ms** 重启（50 ms 延时 + 复位 + 启动） | 【实测】§7.2 |

## 附录 B · 复现命令

```bash
cd v1
./host/tools/py.sh host/tools/servo_probe.py --port /dev/ttyACM1 --repeat 21 \
    --json .test-out/servo_probe.json          # 只读：PING / READ / SYNC_READ
./host/tools/py.sh host/tools/servo_reboot_probe.py --port /dev/ttyACM1 \
    --id 1                                     # 0x08 REBOOT：只写 RAM 增益 50/51 并还原
./host/tools/py.sh host/tools/sensor_probe.py --port /dev/ttyACM1 \
    --json .test-out/sensor_probe.json         # 只读：真 LSM6DSV16X 表征（§7.6）
BUS_PORT=/dev/ttyACM1 ./build.sh smoke         # 传感器感知的协议冒烟（§7.6）
```

沙箱里 `/dev` 被 tmpfs 覆盖（只剩 14 个基础节点），必须用**非沙箱/full access** 运行；
`software/hls_servo_debugger/README.md` 有同样说明，其 `hw_test.py` 是另一份独立的只读
连通性测试（结论一致：ID 1、fw 3.46、mode 4、锁 1、56..70 反馈）。

## 附录 C · 改动的文件（P0/P1）

固件（`v1/src/`）：

* 新增 `us_time.{c,h}`（DWT µs 时基）、`bus_arb.{c,h}`（位次仲裁，纯逻辑）、
  `telem_pack.{c,h}`（契约块打包，纯逻辑）、`critical.h`（极短临界区）；
* `uart_port.{c,h}`：RX 环改成字节回调，TX 改成 DMA（CH3/CH6），回声改成 `tx_busy` +
  时间锚定窗口 `UART_ECHO_WINDOW_BYTES`（固定字节数在真机上被证伪，§4.6.1），
  调试口写入逐字节让路；
* `bus.{c,h}`：帧解析搬进中断回调，新增 `bus_emit()`（立即发 / 按槽延迟）、间隙判据、
  新统计（`deferred`/`tx_lost`/`gaps`）；
* `dev.{c,h}`：`dev_refresh()` 移出读路径并加临界区、契约块、`V_LAST_ERR`、`dev_note_error()`、
  版本/型号、只读范围；
* `fee.{c,h}` / `dxl2.{c,h}`：`sync_named`/`sync_index`、`*_slave_reset()`、FeeTech 恒 0 状态、
  **FeeTech `0x08` REBOOT**（不应答、`dev_request_reboot()`，应用与 bootloader 共用）；
* `gd32f30x_it.c`（DMA 完成中断）、`gd32f30x_libopt.h` + `CMakeLists.txt`（DMA 驱动）、
  `main.c`（发布时机、`loop_max`）、`boot_main.c`/`boot_regs.c`（µs 时基 + boot 侧恒 0）、
  `dbg.c`（去掉 ring 检查）、`board.h`/`bus.h`（常量）；
* 删除 `ring.h`（不再有 RX 环）。

主机（`v1/host/`）：

* 新增 `tools/servo_probe.py`（只读真舵机探针，§1 数据来源）与
  `tools/servo_reboot_probe.py`（`0x08` REBOOT 实测，§1.7）；
* `bus.py`：契约块常量、`ImuBlock.decode(data, protocol)`、`Link.read_contract()`/
  `contract_addr`、飞特 `telemetry_addr` → 128、`device_info()` 读 0..5；
* `tools/bus_smoke.py`：契约块四条断言；`tools/test_protocols.c` + `tools/run_c_tests.sh`：
  新增 4 组用例；`README.md`、`docs/dynamixel_slave.md`、`docs/flash_layout.md`（§9.6）、本文件。

补丁（`v1/patches/`）：`microduck-feetech.patch` 重新生成（burst 2 ms 快速失败 + 故障不中断收集），
`patches/README.md` 同步更新；`feetech.rs` 未改动。

### 真机联调（2026-09-25，§4.6 / §7.6 / §7.7）

* 固件：`src/us_time.{c,h}` + `src/gd32f30x_it.c`（SysTick 里 `us_time_tick()`，修 35.8 s 回绕）、
  `src/uart_port.{c,h}`（回声时间窗口）、`src/imu_spi.{c,h}`（CONVERGE 状态）、
  `src/lsm6dsv16x.h`（`LSM_TAG_SENSOR()`、`LSM_SFLP_CONVERGE_MS`）、
  `src/board.h` / `CMakeLists.txt`（`IMU_USE_SPI`）；
* 主机：新增 `host/tools/sensor_probe.py`（只读表征探针）；`host/tools/bus_smoke.py` 改成
  传感器感知（真/模拟两条路径）；`host/tools/test_protocols.c` 增加 FIFO tag 回归；
* 文档：本文件（§4.6、§7.6、§7.7）、`README.md`、
  `docs/lsm6dsv16x_driver_spec.md`（§8.1 实现状态）。

### 补丁追平上游（2026-09-29）

上游 `microduck` 从补丁基线 `5620aa2`（2026-09-08）前进到 `f0d934e`（2026-09-28，1130 个提交），
补丁按新基线重新生成并重做移植；详见 `patches/README.md`，要点：

* **保留上游新增功能**：替代舵机自动收养（`missing_servos`/`replacement_target`/
  `adopt_replacement`）、`bus.fast_sync_read` 键（在飞特总线上无效果，登记表与文档已写明）；
* **`feetech.rs` 这次有改动**（此前几版都保持逐字节未动）：新增 `sign_magnitude(raw, bit)`，
  删除 `le_i16`。厂商 `HLSCL::ReadSpeed`/`ReadCurrent` 与 `hls_servo_debugger` 都按
  **符号-幅值**（BIT15 方向位）解读速度与电流，原补丁按 `i16` 读取，方向位置 1 时电流会差约
  327 倍、速度在观测向量里同样错；这是本次修掉的真错误；
* `bus.rs`：EEPROM 写（ID 5 / 波特率 6）改为 **先写 55=0 解锁、写值、再写 55=1 回锁**，
  且改 ID 后回锁必须发给**新 ID**（老 ID 上的回锁没人应答，会留下未锁的舵机并报超时）；
  `REBOOT_SETTLE` 从上游 XL330 的 500 ms 改为 **900 ms**（真机实测 823 ms）；
* `Cargo.toml`/`Cargo.lock`：`rustypot 1.8.0` 及其依赖移除（上游为 fast sync read 升的版本，
  飞特总线没有对应指令）；
* 文档：`docs/design/robotd-design.md`（§1.1 加"本树带飞特补丁"提示、总线图、
  `FeetechIo`、fast-sync-read 段落）与 `docs/design/simulation.md`、`deploy/robotd.toml`
  已同步；其余仍描述 XL330 寄存器的段落见补丁说明的未决事项。

### 真机首跑（2026-09-30，15 舵机 + IMU 节点）

第一次把打补丁的 `robotd` 跑在真机上（`/dev/ttyACM0`，速度策略 `2026-09-04_22-59-06_velocity.onnx`）。
完整记录见 `patches/README.md` 第六节，要点：

* 跑通的：`check_registers` 15/15、50 Hz 环路 3858 ticks / 0 missed、策略加载、`robot init`
  归位、**15 个关节实测≈目标（最大偏差 0.02 rad）**——位置标度（4096 counts/圈）与符号-幅值
  编码在真机上成立；电池/温度/四元数都是真值。
* 由此修的两处启动缺陷（`duck-control/src/bus.rs`）：`open()` 后等 `OPEN_SETTLE = 400 ms`
  （CH340 类适配器开端口后第一笔事务必丢，`host/bus.py` 早有同一常数），以及普查里同一个 id
  ping 两次才算缺失（一次丢帧会触发破坏性的改址流程）。
* 真机整定项：`gain = 200` 让 `left_hip_yaw` 自激振荡（5 A、74 °C），厂商默认 32 安静
  （110 mA、温度不升）。默认值已随之改为 32（派生 `gain_limp = 8`、`limp_fall_pose_gain = 26`，
  按原来的 1/4 与 0.8 比例缩），但那是**悬空、无负载、单关节**的台面结论，负载下的整定仍未做。
* 操作提示：同一 tty 只允许一个持有者（`fuser` 检查），`TIOCEXCL` 不会拒绝已存在的 fd。

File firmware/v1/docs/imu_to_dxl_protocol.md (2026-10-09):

# imu_to_dxl v1 通信协议参考（外部主机实现者版）

本文是 `imu_to_dxl` v1 节点的**自包含**通信协议参考，面向用任意语言自行实现主机/主站
（master）的外部开发者。读完本文即可实现：读遥测、读写配置、触发动作、以及**通过同一条
电机总线给节点升级固件**。

文中所有数字、地址、位域、操作码与常量都标了出处：源码用 `文件:行`（例如 `src/board.h:301`），
设计文档用 `文档 §节`。**没有出处、又无法从仓库确认的值，一律不写，集中列在 §15.5
「未在仓库中找到」**。标注约定：

* **【实测】** = 在真硬件上量到的数字（真实舵机 / 本节点 / 真 PCBA）。
* **【设计】** = 固件里定死的设计值或设计选择，不是测量结果。
* **【源码】** = 直接读代码得到的事实。
* **【估算】** = 由实测常数推算，不是直接测量。

**固件版本见 §13**（注意：节点寄存器里报的固件版本与
升级镜像头里的版本号不是同一个数，见 §13.1）。

---

## 1. 概览

### 1.1 节点是什么

`imu_to_dxl` v1 是一块 **GD32F303CC**（LQFP48，256 KB Flash / 48 KB SRAM，12 MHz 晶振 →
120 MHz，`src/board.h:5-6`）节点板。它把一个 **20 字节的 IMU 数据块**发布成**伺服总线上的一个
从站**，让主机在同一次总线上同时读到姿态与全部舵机状态（`README.md:1-5`）。

真实机器人上的拓扑（`README.md:11-15`、`docs/bus_timing_borrow_plan.md:346-353`）：

* 节点与 **15 颗 FeeTech HD-1910-C001** 舵机（ID `10-14`、`20-24`、`30-34`）**并联**在
  同一条 **1 Mbps 半双工**伺服总线上；
* 节点 ID = **200**；
* 主机（PC / 机器人主控）经 **USB 串口适配器**接到这条总线；
* 节点使用与舵机**相同的总线电气层与帧格式**，所以总线上其它舵机看到的只是"发给 ID 200 的
  普通读写"，主机不需要为舵机加任何特殊逻辑（`docs/upgrade.md:196-199`）。

节点是**从站**：它**只应答，从不主动发送**（【源码】唯一的发送路径都来自收到并解析出一帧之后，
`src/bus.c:126` 与 `src/bus.c:275`；主循环的 `bus_poll()` 只负责把"等自己应答槽"的延迟应答发出去，
`src/bus.c:262-282`）。

### 1.2 两种协议人格，一条总线

节点在**同一个物理端口**上同时实现了两套协议，按帧的**第 3 个字节**自动识别
（`src/bus.h:13-17`）：

| 人格 | 协议 | 帧头 | 校验 |
|---|---|---|---|
| **Dynamixel 2.0** | ROBOTIS Protocol 2.0 | `FF FF FD 00` | CRC-16（整帧，含帧头） |
| **FeeTech SCS/HLS** | 飞特 SCS/HLS（HD-1910 系列） | `FF FF <ID>` | `~SUM`（8 位取反和） |

两套协议共用同一个节点 ID（默认都是 200）与**同一组遥测/配置语义**，但**地址映射不同**
（Dynamixel 跟随 XL330 控制表，FeeTech 跟随 HLS 内存表），见 §7。

### 1.3 主机能用它做什么

| 能力 | 手段 | 章节 |
|---|---|---|
| 读遥测（陀螺 / 四元数 / 加速度 / 计数 / 状态位） | `READ` / `SYNC_READ` | §6、§11 |
| 与 15 颗舵机一次 `sync_read` 读完 | FeeTech 地址 56、长度 **15** | §6.2 |
| 与 15 颗舵机一次 **`fast_sync_read`（`0x8A`）**读完（Dynamixel 路线，省掉每台的帧头与转向） | `0x8A`，ID 列表把本节点放第 0 位；应答是一个 `ID=0xFE` 的聚合帧 | §3.2.1、§11(c2) |
| 读/写配置（ID、波特率、安装系、陀螺偏置、模拟模式、调试级别、协议锁） | 厂商配置窗（DXL 148 / Fee 160，20 字节） | §8 |
| 触发动作（保存配置、恢复出厂、重启、重启融合、确认 trial 镜像、切槽、进 bootloader） | 厂商窗 `V_CMD` 命令 1~7 | §8.4 |
| 识别固件状态（应用 / bootloader、槽、版本、镜像 CRC、trial 状态） | 身份窗（180..195，只读） | §9 |
| **通过同一条总线升级固件** | 升级会话窗（208..255）+ `.ipkg` 包 | §10 |

### 1.4 固定项（默认值 + 持久化）

以下值有出厂默认，且**可改写并保存到 Flash**，所以对某个具体节点应当以读回值为准，而不是
假定默认值：

| 项目 | 默认 | 出处 |
|---|---|---|
| Dynamixel ID（寄存器 7） | **200** | `src/board.h:301`、`src/dev_cfg.c:19` |
| FeeTech ID（寄存器 5） | **200** | `src/board.h:305`、`src/dev_cfg.c:21` |
| Dynamixel 波特率码（寄存器 8） | **3** = 1 Mbps | `src/board.h:315`、`src/dev_cfg.c:20` |
| FeeTech 波特率码（寄存器 6） | **0** = 1 Mbps | `src/board.h:317`、`src/dev_cfg.c:22` |
| Dynamixel 遥测块地址 | **124**（20 字节） | `src/board.h:449` |
| FeeTech 契约块地址 | **56**（15 字节） | `src/board.h:450`、`src/board.h:457` |
| FeeTech 诊断块别名地址 | **128**（20 字节） | `src/board.h:451` |
| Dynamixel 厂商窗 | **148..167** | `src/board.h:471` |
| FeeTech 厂商窗 | **160..179** | `src/board.h:472` |
| 身份窗 / 升级窗（两种协议同址） | **180..195** / **208..255** | `src/board.h:184-185`、`src/board.h:222-223` |

ID 与波特率写入后会被节点**夹紧到合法范围并持久化**：Dynamixel ID 限 1..252
（`src/dev.c:307-311`），FeeTech ID 限 0..252（`src/dev.c:320-324`，`FEE_ID_MAX = 252`，
`src/board.h:306`）；波特率码非法时忽略并回写旧值（`src/dev.c:313-331`）。**FeeTech ID 禁止
253（0xFD）**，因为它是 Dynamixel 2.0 的帧头字节（`src/board.h:302-306`、`src/fee.c:323-329`）。

---

## 2. 物理层与总线参数

| 项目 | 值 | 出处 |
|---|---|---|
| 总线 | 单线**半双工**，所有节点并联；任意时刻只能有一个发送方 | `飞特通讯协议说明.md §1` |
| 电平 | TTL 3.3 V | `飞特通讯协议说明.md §1` |
| 帧格式 | **8N1**（8 数据位、无校验、1 停止位），无流控 | 【源码】`src/uart_port.c:99-101`；`飞特通讯协议说明.md §1` |
| 默认波特率 | **1 Mbps**（Dynamixel 码 3 / FeeTech 码 0） | `src/board.h:308-317`；波特率表 `src/dev.c:592-605` |
| 节点主总线 | USART1，PA2 = TX / PA3 = RX | `src/board.h:21-23`、`src/board.h:352-355` |
| 调试口 | USART0，PB6 = TX / PB7 = RX；**只输出 DBG_ 日志**（115200），不应答协议帧。`BUS_MIRROR_ENABLE=1`（台架实验构建，默认 **0**）才把它也当第二协议端口；**即使打开，升级会话在那边仍被拒绝**（§10.2） | `src/board.h:30-31,62-75,310-311`、`src/bus.c:213-241` |
| 方向控制 | **硬件自动方向**：原理图里 `TXD_EN` 由 TX 直接产生（Q1 + R28/R29/C22），固件不控制任何 GPIO | `src/board.h:21-23`、`README.md:78` |

要点：

1. **半双工单线，同一时刻只有一个发送方。** 主机必须严格按照"一帧请求 → 等应答（或超时）
   → 下一帧"的节奏；不要流水式连发（`docs/upgrade.md` 的升级流程、`src/bus.c:262-282` 的
   请求-应答结构都依赖这一点）。
2. **自动方向缓冲把主机的 TX 变成总线驱动**，主机侧必须使用支持 1 Mbps 且方向自动切换的
   半双工/USB-TTL 适配器；台面用的是 CH340（`docs/upgrade.md:305`、`docs/bus_timing_borrow_plan.md:63`）。
3. **节点能听到自己的发送**（半双工回声）。固件在发送期间以及发送完成后一个**按波特率计算的
   时间窗**（`UART_ECHO_WINDOW_BYTES = 3` 个字节时间，1 Mbps 下 ≈30 µs）内丢弃收到的字节
   （`src/uart_port.h:22-34`、`src/uart_port.c:26-38,251-253`）。主机不需要知道这个窗口，但
   应当知道节点在应答后极短时间内可能收不到紧随的字节——现实中主机下一帧至少是毫秒级，
   远在窗口之外。
4. **节点上电后立即可应答**：文档给出的验收目标是上电 ≤ 50 ms 内可应答（`docs/bus_timing_borrow_plan.md:423`），
   **但这一项尚未实测**（同处标注"未测"），所以不要把它当成保证，见 §15.5。
5. 本文只描述**电机总线**。USART0 是**调试口**：只输出 DBG_ 日志，默认不解析任何帧
   （`BUS_MIRROR_ENABLE = 0`）；台架实验构建把它也当协议口，但**升级会话在那里一律被拒**
   （§10.2）。调试文本行以 `#` 开头，ASCII 里没有 `0xFF`，所以即使两个口接在同一台 PC 上
   也不会被误认成帧（`src/dbg.c`）。

---

## 3. 帧格式与协议识别

### 3.1 Dynamixel 2.0 指令帧（主机 → 节点）

与 rustypot 1.6 / ROBOTIS Protocol 2.0 逐字节一致（`src/dxl2.h:8-11`、`docs/dynamixel_slave.md:14-20`）。

| 偏移 | 字节数 | 字段 | 说明 |
|---|---|---|---|
| 0 | 1 | `0xFF` | 帧头 |
| 1 | 1 | `0xFF` | 帧头 |
| 2 | 1 | `0xFD` | 协议 2.0 标识（**也是协议自动识别的判据**，见 §3.8） |
| 3 | 1 | `0x00` | 保留 |
| 4 | 1 | `ID` | 目标 ID（`0xFE` = 广播，`src/board.h:380`） |
| 5 | 1 | `LEN_L` | 长度低字节 |
| 6 | 1 | `LEN_H` | 长度高字节 |
| 7 | 1 | `INST` | 指令码（§5.1） |
| 8 | `N` | `PARAM...` | 参数（**已做字节填充**，见 §3.4） |
| 8+N | 1 | `CRC_L` | CRC-16 低字节 |
| 9+N | 1 | `CRC_H` | CRC-16 高字节 |

* **`LEN = len(参数) + 3`**（3 = INST + 2 字节 CRC），**整帧 = 7 + LEN**（`src/dxl2.c:179-180`、
  `host/bus.py:213-222`）。
* `LEN` 统计的是**填充后**的参数长度（`host/bus.py:220`）。
* 节点收帧时先按 `LEN` 收满整帧，再校验 CRC，再对 `f[8 .. LEN-3]` 去填充
  （`src/dxl2.c:570-597, 107-114`）。

### 3.2 Dynamixel 2.0 状态帧（节点 → 主机）

| 偏移 | 字节数 | 字段 | 说明 |
|---|---|---|---|
| 0..3 | 4 | `FF FF FD 00` | 帧头 |
| 4 | 1 | `ID` | 本节点 ID（恒为本机 ID，即使收到的是广播 PING） |
| 5..6 | 2 | `LEN_L LEN_H` | 长度，**统计填充后的字节** |
| 7 | 1 | **`0x55`** | **状态标记**：指令帧这里是 `INST`，状态帧这里是固定值 `0x55`（`src/board.h:385-386`） |
| 8 | 1 | `ERR` | 错误位（§5.3） |
| 9.. | `n` | `PARAM...` | 参数（**已填充**） |
| 末 2 | 2 | `CRC_L CRC_H` | CRC-16 |

* **`LEN = 1(标记) + 1(ERR) + len(参数) + 2(CRC)`**，无填充时 = `len(参数)+4`；整帧 = `7 + LEN`
  （`src/dxl2.c:53-55`、`docs/dynamixel_slave.md:25-28`）。
* 状态帧的 **`ERR + PARAM`（即body）整体被字节填充**，`LEN` 与 CRC 都按填充后的样子计算
  （`src/dxl2.c:22-24,50-70`）。主机必须在 **CRC 校验通过之后**才去填充
  （`host/bus.py:269-274`）。

#### 3.2.1 Fast Sync Read（`0x8A`）的聚合状态帧

`0x8A` 的**指令帧与 `0x82` 逐字节相同**（只换 opcode：`src/board.h:416`），不同在应答：
所有被点名的设备**共同拼出一个**状态帧，`ID` 是广播 `0xFE`：

| 发出者 | 字节 |
|---|---|
| ID 列表**第 0 台**设备（只有它发） | `FF FF FD 00 FE LEN_L LEN_H 0x55` |
| 每台被点名的设备，按 ID 列表顺序 | `ERR ID DATA(X) CRC_L CRC_H` |

规则（【外部】ROBOTIS protocol 2.0 手册 "Fast Sync Read (0x8A)"；【源码】`src/dxl2.c:75-171`
与 `src/dxl2.c:373-434`；【实测】§11(c2)）：

* **`LEN = 1(标记) + N × (X + 4)`**，`N` = ID 列表长度，`X` = 指令里的读长。它**覆盖整包**，
  不是本机那一段：16 台设备各读 12 字节 → `LEN = 257`，整帧 264 字节，而本节点只发 24 字节。
* 每段的 `ID` 是**设备自己的 ID**（不是 `0xFE`）；`ERR` 是它自己的错误位（§5.3）。主机按 ID
  列表顺序逐段取数，段的 ID 与请求不符即整包无效。
* **每段末尾的 CRC 覆盖"从头到本段数据末尾"**（含前面所有段和 8 字节前缀）。主机因此可以逐段
  校验，这也正是"段的位置对不对"的判据；**最后一台的 CRC 就是整包的 CRC**（`0x82` 那种单帧
  校验器用 `LEN` 切出整包后照样能过 `dxl_parse_status`，但它看到的是原始各段字节）。
* **不做字节填充**：数据里出现 `FF FF FD` 时原样发出，主机必须按 `LEN` 定长切分（官方 SDK 读
  这类包时明确跳过去填充，rustypot 同样按 `LEN` 切）。§11(c2) 有反证向量。
* **"轮到自己"的判据是字节数，不是时间槽**：本机排在第 k 位时必须等到前面 k 段上线才能算出
  自己的 CRC，所以它数到 `8 + k × (X + 4)` 字节就发（`src/dxl2.c:601-643`、`src/bus.c:179-188`）。
  排在第 0 位时无需等待，**路径与 `0x82` 完全相同**——收完指令在 USART 中断里直接交给 DMA
  （`src/dxl2.c:152-171`）。microduck 的 tick 读正是这个布局。
* **错误也要保持段长**：越界读长报 `ERR = 0x10`、数据补 0；读长 > 256 或不含本机 → 静默。
  （`0x82` 是回一个*不含数据*的错误状态帧，在 `0x8A` 里那样做会让后面所有段错位。）
* `STATUS_RETURN_LEVEL = 0`、ID 列表不含本机、`LEN` 无法用 16 位表达 → **静默**。
* **`0x8A` 若指向本机（非广播）且本机不在第 0 位**：前面那些设备根本没被点名、不会发言，本机
  收不到前缀就把这次应答**作废**（`src/dxl2.c:610-624`），不会把一段属于"不存在的包"的块发到
  总线上。
* **"第一个字节还没来"与"流断在半路"不是一回事**：前导设备允许先等自己的 `return_delay_time`
  再开口（出厂值 250 ⇒ 500 µs，比本节点 500 µs 的帧内间隔阈值还长），所以本节点在**收到第一个
  字节之前**遇到空闲间隔**不作废**这次应答；一旦开始收字节再出现 > 500 µs 的间隔，就按"包已断"
  作废（`src/dxl2.c:508-528`）。两条行为都有宿主测试钉住。
* **实现注记（对固件维护者）**：本节点解析一整帧必须在**一个字节时间**（1 Mbps 下 10 µs）内
  做完，否则紧跟其后的字节会被 USART 的单字节接收寄存器覆盖丢掉——`0x8A` 的聚合帧正是"紧跟
  指令帧"发言的第一个例子。因此 CRC-16 是查表实现（`src/crc16.c:16-55`），不是按位循环。
  详见 `docs/bus_timing_borrow_plan.md §7.8`。

### 3.3 CRC-16（Dynamixel）

参数（`src/crc16.h:4-9`）：

| 参数 | 值 |
|---|---|
| 多项式 | `0x8005` |
| 初值 | `0x0000` |
| 位序 | **高位在前（MSB first，不反射）** |
| 最终异或 | 无 |
| 覆盖范围 | **整帧，含 `FF FF FD 00` 帧头，直到 CRC 字段之前** |

逐字节算法（`src/crc16.c`、`host/bus.py:160-170`）：

```
crc = 0
for byte in frame_without_crc:
    crc ^= (byte << 8)
    for _ in range(8):
        if crc & 0x8000: crc = ((crc << 1) ^ 0x8005) & 0xFFFF
        else:            crc = (crc << 1) & 0xFFFF
```

**已算好的向量**（`host/bus.py:980-982`、`host/tools/test_crc16.c`）：对 `FF FF FD 00 02 03 00 01`
（PING，ID=2）CRC = **`0x7219`**，完整帧 = `FF FF FD 00 02 03 00 01 19 72`。

### 3.4 字节填充（byte stuffing）

协议 2.0 规定：**当参数/body 中出现 `FF FF FD` 时，必须在其后再插入一个 `0xFD`**；
**`LEN` 与 CRC 都按填充后的字节计算**；接收方**只在 CRC 校验通过后**才去掉填充
（`docs/dynamixel_slave.md:41-47`）。

本节点的精确规则（`src/stuffing.c:13-45`，与官方 DynamixelSDK `addStuffing` 一致）：

1. 模式扫描**只在原始字节上进行**，插进去的 `0xFD` 不会再触发新的匹配；
2. 连续 `0xFF` 的计数在 `FF FF FF` 时**保持为 2**（"`FF FF` 后缀"在多余 `FF` 之间继续有效），
   所以 `FF FF FF FD` 也要插一个字节；
3. 匹配到"已有两个连续 `0xFF` 且当前字节是 `0xFD`"时，输出 `0xFD` 后再补一个 `0xFD`。

**已核对的向量**（`host/bus.py:999-1009`、`docs/dynamixel_slave.md:54-61`）：

| 输入 | 输出 |
|---|---|
| `01 02 FF FD 03` | `01 02 FF FD 03`（没有 `FF FF FD`） |
| `FF FF FD 07` | `FF FF FD FD 07` |
| `FF FF FD FD` | `FF FF FD FD FD` |
| `FF FF FF FD` | `FF FF FF FD FD` |

**一个真实的状态帧演练**（用 `host/bus.py` 的编解码函数计算，CRC 已核对）：

假设主机读 20 字节，参数（数据）以 `FF FF FD` 开头，body（`ERR + 参数`）为
`00 FF FF FD` + 17 个 `0x00` = 21 字节：

* 填充后 body = `00 FF FF FD FD` + 17 个 `0x00` = **22 字节**；
* `LEN = 22 + 3 = 25 = 0x19`；
* 线上帧 = `FF FF FD 00 C8 19 00 55 00 FF FF FD FD 00 …(17×00)… CRC_L CRC_H`；
* 如果**不填充**，`LEN` 就会算成 `0x18`，接收方（rustypot 会调用 `remove_stuffing`）
  会把后面的参数整体错位——这正是 §12 里"必须填充"的原因。

主机侧去填充只对**状态帧的 body**（`frame[8:-2]`）做（`host/bus.py:194-210,271`）。

### 3.5 FeeTech SCS/HLS 指令帧（主机 → 节点）

| 偏移 | 字节数 | 字段 | 说明 |
|---|---|---|---|
| 0 | 1 | `0xFF` | 帧头 |
| 1 | 1 | `0xFF` | 帧头 |
| 2 | 1 | `ID` | `0xFE` = 广播（`src/board.h:422`）；**禁止 `0xFD`** |
| 3 | 1 | `LEN` | 见下 |
| 4 | 1 | `INST` | 指令码（§5.2） |
| 5 | 1 | `ADDR` | 地址（只有带地址的指令才有此字节） |
| … | `n` | `DATA...` | 数据 |
| 末 | 1 | `~SUM` | 校验和 |

* **`LEN = len(params) + 2`**，其中 `params = ADDR + DATA`（无地址的指令就是只有 DATA 的
  `INST` 计数）；`LEN` 统计 **INST + ADDR + DATA + SUM**；整帧 = `LEN + 4`
  （【源码】`src/fee.c:67-68`；`飞特通讯协议说明.md §2.1`）。
  官方参考库把它写成 `LEN = 数据长度 + 3`（PING 时为 2），两者一致
  （`飞特通讯协议说明.md:58`）。
* 节点要求 `LEN >= 2`，否则丢弃并计 `bad_len`（`src/fee.c:336-341`）。
* 多字节数据**小端**（低位字节在低地址，`飞特通讯协议说明.md §6`）。

### 3.6 FeeTech 应答帧（节点 → 主机）

| 偏移 | 字节数 | 字段 | 说明 |
|---|---|---|---|
| 0..1 | 2 | `FF FF` | 帧头 |
| 2 | 1 | `ID` | 本节点 ID |
| 3 | 1 | `LEN` | **`LEN = len(DATA) + 2`**（2 = STATUS + SUM） |
| 4 | 1 | `STATUS` | **本节点恒为 `0x00`**（见 §5.4） |
| 5.. | `n` | `DATA...` | 数据（READ 的数据、SYNC_READ 的数据；其它指令为空） |
| 末 | 1 | `~SUM` | 校验和 |

【源码】`src/fee.c:37-61`。整帧 = `LEN + 4`。

### 3.7 FeeTech 校验和 `~SUM`

定义（`src/fee.c:72-90`；`飞特通讯协议说明.md §2.1-2.2`）：

```
SUM = ID + LEN + INST + ADDR + Σ DATA      # 无地址的指令：ADDR 按 0 参与求和
线上字节 = (~SUM) & 0xFF
```

* **覆盖范围**：从 `ID` 到**最后一个数据字节**（不含 `~SUM` 自身）。应答帧同理，从 `ID` 到
  最后一个数据字节（`src/fee.c:56-59`）。
* 发送无地址的指令（PING / REG_ACTION / RESET / CAL）时，`ADDR` 不在帧里出现，但**必须按 0
  参与求和**——本节点的校验循环只累加帧内真实字节，因此天然符合
  （`src/fee.c:81-83`；`飞特通讯协议说明.md:61-63`）。
* **校验错误的帧完全不应答**（SCS 协议没有"校验错应答"）；本节点计 `bad_sum` 后直接
  丢弃（`src/fee.c:84-90`）。真舵机实测同样静默（`docs/bus_timing_borrow_plan.md §1.4`）。

**已核对的向量**（`host/bus.py:1012-1014`、`飞特通讯协议说明.md §2.3`）：

| 帧 | 字节 |
|---|---|
| PING 指令（ID 200） | `FF FF C8 02 01 34`（`SUM = C8+02+01 = CB`，`~CB = 34`） |
| PING 应答 | `FF FF C8 02 00 35` |
| READ(56, 12) 指令 | `FF FF C8 04 02 38 0C ED` |

### 3.8 协议识别、100 ms 粘滞与强制锁定

**识别判据**：一帧的第 3 个字节为 **`0xFD` ⇒ Dynamixel 2.0**，否则 ⇒ **FeeTech**
（`src/bus.h:13-17`）。实现上两个解析器同时喂入：

* FeeTech 解析器在第 3 字节是 `0xFD` 时**直接拒绝并复位**（`src/fee.c:323-329`）；
* Dynamixel 解析器要求第 3 字节是 `0xFD`（`src/dxl2.c:549-556`）；
* 两者都要求前两字节是 `FF FF`（`src/dxl2.c:535-548`、`src/fee.c:308-322`）。

**100 ms 粘滞**（【设计】`BUS_PROTO_STICKY_MS = 100`，`src/bus.h:42-47`）：节点**成功应答过**
某一种协议后，该端口在 **100 ms** 内**只认这种协议**（`src/bus.c:63-92`）。目的：防止
Dynamixel 载荷里恰好的 `FF FF <本机 ID>` 被误判成 FeeTech 帧，同时让主机切换协议不必等一秒。

对一个主机实现者的**实际后果**（这一点在真机上踩过，`docs/bus_timing_borrow_plan.md §7.2`
的"主机侧测量注意"）：

> 如果先做了一次 Dynamixel 事务、紧接着（**< 100 ms**）发 FeeTech 帧，节点会把它当噪声
> **静默忽略**；现象是"命令没反应 / 设备像死了一样"。反过来也一样。

修复办法（任选其一）：

1. 同一会话里**只用一种协议**；
2. 切换协议前**等 > 100 ms**；
3. 先发一帧同协议请求把端口"粘"到目标协议上；
4. 用厂商窗 `V_PROTO_LOCK`（偏移 9；0=自动 / 1=仅 Dynamixel / 2=仅 FeeTech，`src/board.h:486`、
   `src/dev.c:247-250`、`src/bus.c:63-75`）**强制锁定**。写 `V_PROTO_LOCK=1` 或 `2` 后该端口
   对另一种协议的帧一律不解析。

一个细节：粘滞时间戳是**在节点发出应答时**更新的（`src/bus.c:88-92,103`，`bus_emit()` 是唯一
调用点）。因此**不应答的请求（例如广播写、ACK 级别 0 下的静默写）不会刷新这 100 ms 窗口**。

---

## 4. 时序契约（主机实现者必须遵守）

本节全部是**硬契约**：违反它不会得到"慢一点"的结果，而是丢失整条 `sync_read` 的全部数据。

### 4.1 只允许请求/应答

节点**从不主动发送**（`src/bus.c`：发送路径只有 `bus_emit()` 与 `bus_poll()`，两者都由收到
帧触发）。主机不得假设节点会周期广播，也不得在发出请求后立即改变总线方向做别的事。

### 4.2 应答槽规则（reply slot）

真舵机在 `sync_read` 中**不立即应答**：它会为 ID 列表里**每一个排在自己前面的 ID** 等一个
"应答槽"，**无论那台设备在不在线**。实测（【实测】`docs/bus_timing_borrow_plan.md §1.3`）：

| 用例（真 HD-1910，fw 3.46，1 Mbps） | 首字节 | 相对基线 |
|---|---|---|
| `SYNC_READ [1]` | 0.526 ms | 基线 |
| `SYNC_READ [7,1]`（前 1 个**缺席**） | 0.828 ms | **+0.302 ms** |
| `SYNC_READ [7,8,1]`（前 2 个缺席） | 1.121 ms | **+0.595 ms**（+0.297/个） |
| `SYNC_READ [7,8,9,1]`（前 3 个缺席） | 1.408 ms | **+0.882 ms**（+0.294/个） |

* **槽长 ≈ 295 µs**（0.294–0.302，n=21×3）。它约等于一个 21 字节应答的线上时间 210 µs +
  ≈85 µs 空隙（【实测/推算】`docs/bus_timing_borrow_plan.md §1.3`、`附录 A`）。
* **缺席设备照样占一槽**，不是"长时间超时"。所以"用总线静默 1 ms 判断缺席"是错的：k=1 时
  应答窗口 295 µs 就开了，等 1 ms 会晚一整槽并撞上后面的设备
  （`docs/bus_timing_borrow_plan.md:36,50,109`）。
* 本节点使用 **`BUS_SLOT_US = 300`**（300 µs，往上取整）作为自己的槽模型（`src/board.h:462-468`）。

### 4.3 本节点的延迟应答（k > 0 时让 k 个槽）

当 `sync_read` 的 ID 列表里本节点下标为 **k > 0** 时，节点**不立即发送**，而是先让出 **k 个槽**
再发（`src/dxl2.c:354-367`、`src/fee.c:232-242` 记录 `sync_index`；`src/bus.c:112-122` 延迟；
`src/bus_arb.c:33-44,85-98` 计时）：

* 等待期间若出现**新的、指向本机 ID 或广播的指令帧**，本次延迟应答**作废**
  （`src/bus_arb.c:46-83`；Dynamixel 的 ID 在第 5 字节，FeeTech 的 ID 在第 3 字节，靠第 3
  字节是否为 `0xFD` 区分）；
* 等待期间只收不发是合法的（半双工单线）。

**对主机的意义**：

1. 如果主机把节点排在 ID 列表**中间或末尾**，节点的应答会**晚 k × 300 µs** 到达（真机实测
   本节点延迟路径的斜率 ≈330 µs/槽，`docs/bus_timing_borrow_plan.md §7.3`：前导 ID 全缺席时
   `[200]` 基线、`[7,200]` +339 µs、`[7,8,200]` +676 µs、`[7,8,9,200]` +1001 µs）。
2. 主机**必须按 ID 匹配应答**（扫描缓冲里的 `FF FF`、用 `LEN` + 校验和确认），**不要假设
   应答按请求顺序到达**，也不要因为节点"该答却没立刻答"就判它掉线
   （`飞特通讯协议说明.md §4.1`、`host/bus.py:690-738`）。
3. 运行时（机器人控制环）**总是把 IMU 节点排在列表第 0 位**，所以热路径"收完指令立即发"
   （`src/bus.c:12-16`、`docs/dynamixel_slave.md:192`）。

> **`0x8A`（Fast Sync Read）不适用本节。** 它的应答不是各发各的状态帧，而是所有设备共拼一个
> 聚合帧（§3.2.1），每段只有约 `(X+4)×10 µs`，比 300 µs 的槽短，所以 `k > 0` 时**不能**按槽
> 让位，而是数前面 k 段的字节（`src/dxl2.c:601-643`）。`0x8A` 的 ID 列表把本节点放在第 0 位
> 仍然最省，但那是不用等，不是因为会撞包。

### 4.4 帧内字节间隙与整帧超时

* **字节间隙规则**：若**帧解析进行中**，相邻字节间隔 > **`BUS_GAP_US = 500 µs`**，则丢弃
  已收到的残帧，并在下一个 `FF FF` 上重新同步（`src/bus.h:53-56`、`src/bus.c:159-170`）。
  空闲间隔（两次事务之间）不算故障（`src/bus.c:161-163`）。
* **整帧超时**：若一帧已开始但 20 ms 内没有收完，状态机复位（`DXL_FRAME_TIMEOUT_MS = 20`，
  `src/dxl2.c:15,527-531`；`FEE_FRAME_TIMEOUT_MS = 20`，`src/fee.c:13,301-305`）。
* 因此主机**不要在一帧中间停顿超过 500 µs**；1 Mbps 下一个字节 10 µs（`docs/bus_timing_borrow_plan.md:601`）。

### 4.5 一次 16 设备组合 `sync_read` 的实测往返

真 PCBA + 15 颗真舵机，主机直接发"ID 200 + 15 颗舵机"的一次 `sync_read`（FeeTech 地址 56、
长度 15），【实测】`docs/bus_timing_borrow_plan.md §7.7`（`README.md:438`）：

| 指标 | 值 |
|---|---|
| 主机**往返**（含 USB CDC） | 中位 **8.74 ms** / p95 8.86 ms / max 8.95 ms |
| 完整性（扭矩关 / 扭矩开 / 背靠背） | 150/150 / 150/150 / 200/200 |
| 节点侧 | 每秒约 47/50 次读被应答，`echo=0 dropped=0 err=0` |

**注意区分**：8.74 ms 是**含 USB CDC 的主机往返**（【实测】）；总线上的纯串行时间由槽长
**推算**为 240 µs（指令）+ 210 µs（本节点 15 字节应答）+ 15 × 295 µs ≈ **4.9 ms**
（【估算】`docs/bus_timing_borrow_plan.md §2`）。4.9 ms 不是测量值。

主机侧还需要知道：**USB 适配器可能整块丢一次回复**（不是设备掉线）。2026-09-25 在真机 15 舵机
总线上实测到"缺失集合总是回复到达顺序的尾部，形状像一个 USB 传输块被整块丢掉"
（【实测】95 次里 60 次只收到 `200`，其余是按到达顺序连续的一段舵机 ID；同一条总线上直连的
16 ID 读 150/150 完整，数字见 `docs/bus_timing_borrow_plan.md §7.7`）。主机应**容忍/有限重试
缺失的回复**，而不是判定节点故障。

---

## 5. 指令集

### 5.1 Dynamixel 2.0（opcode 来源 `src/board.h:397-418`，行为来源 `src/dxl2.c`）

ID 过滤：只处理 `ID == 本机 ID` 或 `ID == 0xFE`（广播）的帧，其它一律静默忽略
（`src/dxl2.c:215-221`）。

| INST | 名称 | 方向 | 节点行为 | 出处 |
|---|---|---|---|---|
| `0x01` | PING | 主→从 | **总是应答**（广播也答，用本机 ID），参数 = 型号(2, LE) + 固件版本(1)；bootloader 里型号变成 `0xB007`、版本 0 | `src/dxl2.c:226-238`；`src/board.h:160` |
| `0x02` | READ | 主→从 | 参数 `ADDR(2) + LEN(2)`；应答 `LEN` 字节。参数个数 ≠ 4 → `ERR=0x08`；`LEN > 256` → `ERR=0x08`；地址越界 → `ERR=0x10`；`STATUS_RETURN_LEVEL = 0` → 静默 | `src/dxl2.c:240-264` |
| `0x03` | WRITE | 主→从 | 参数 `ADDR(2) + DATA`；整段写，**只要碰到一个只读字节就整帧拒绝**（`ERR=0x02`）。广播写执行但**不应答**；`STATUS_RETURN_LEVEL < 2` 时也不应答 | `src/dxl2.c:266-281`；`src/dev.c:762-774` |
| `0x04` | REG_WRITE | 主→从 | 暂存写入（最多 `DXL_PEND_MAX = 32` 字节，`src/dxl2.h:33`），等 `ACTION` 执行；除非广播，否则应答 | `src/dxl2.c:283-301` |
| `0x05` | ACTION | 主→从 | 执行暂存的 `REG_WRITE`；即使没有暂存也应答（非广播） | `src/dxl2.c:303-315` |
| `0x06` | FACTORY_RESET | 主→从 | 恢复出厂默认**并立即写 Flash**；除非广播，否则应答 | `src/dxl2.c:317-323`；`src/dev.c:842-849` |
| `0x08` | REBOOT | 主→从 | 先回应答，**50 ms 后软复位**；除非广播，否则应答 | `src/dxl2.c:325-331`；`src/dev.c:836-840` |
| `0x10` | CLEAR | 主→从 | 清硬件错误状态（地址 70/71）；广播或 `STATUS_RETURN_LEVEL < 2` 时静默 | `src/dxl2.c:333-339`；`src/dev.c:823-851` |
| `0x82` | SYNC_READ | 主→从 | 参数 `ADDR(2) + LEN(2) + ID...`；**仅当 ID 列表包含本机 ID 时**读并应答，并按自己的下标 k 让 k 个槽；不在列表 → 静默；`LEN > 256` 或 `STATUS_RETURN_LEVEL = 0` → 静默；参数 < 4 → 静默 | `src/dxl2.c:341-371`；`src/bus.c:112-122` |
| `0x83` | SYNC_WRITE | 主→从 | 参数 `ADDR(2) + LEN(2) + (ID + DATA)×N`；命中本机 ID 就写；**永不应答** | `src/dxl2.c:436-460` |
| `0x8A` | FAST_SYNC_READ | 主→从 | 指令同 `0x82`；应答是**所有设备共拼的聚合状态帧**（§3.2.1）：`LEN = 1 + N×(X+4)` 覆盖整包，每段 `ERR + ID + DATA + 累积 CRC`，**不填充**，第 0 台额外发 8 字节前缀。本机排第 k 位时按前面 k 段的**字节数**让位（不是槽）；越界读长仍保持段长、数据补 0；不含本机 / `level = 0` / 参数 < 4 / `LEN` 超 16 位 / 前缀对不上 → 静默 | `src/dxl2.c:373-434`、`src/dxl2.c:75-171,601-643`、`src/bus.c:131-146,179-188`、`src/board.h:416` |
| `0x92` | BULK_READ | 主→从 | 参数布局 `(ADDR(2), LEN(2)) × N + ID × N`（共 7N 字节）；本机 ID 在列表里才应答；参数 < 7 或不是 7 的倍数 → 静默 | `src/dxl2.c:462-490` |
| 其它 | — | — | **拒绝**：回 `ERR = 0x40`（Instruction Error）；广播时静默 | `src/dxl2.c:492-498` |

**`STATUS_RETURN_LEVEL`（寄存器 68，默认 2，`src/dev.c:176`）的精确语义**（【源码】`src/dxl2.c`）：

| level | PING | READ / SYNC_READ / FAST_SYNC_READ / BULK_READ | WRITE / CLEAR | REG_WRITE / ACTION / FACTORY_RESET / REBOOT |
|---|---|---|---|---|
| 0 | 应答 | **静默** | **静默** | 应答（非广播） |
| 1 | 应答 | 应答 | **静默** | 应答（非广播） |
| 2 | 应答 | 应答 | 应答 | 应答（非广播） |

（`docs/dynamixel_slave.md:86-87` 把 level 1 概括成"PING + READ/SYNC_READ"，不够精确；
见 §15.6。）

### 5.2 FeeTech SCS/HLS（opcode 来源 `src/board.h:420-437`，行为来源 `src/fee.c`）

ID 过滤：只处理 `ID == 本机 ID` 或 `ID == 0xFE`（广播）。

| INST | 名称 | 方向 | 节点行为 | 出处 |
|---|---|---|---|---|
| `0x01` | PING | 主→从 | 应答 `FF FF ID 02 00 ~SUM`（无数据） | `src/fee.c:103-105` |
| `0x02` | READ | 主→从 | 参数 `ADDR(1) + nLen(1)`；应答 STATUS + nLen 字节。`LEN<4` 或 `nLen=0` → 回一个**空**ACK；地址/长度越界 → 回**空** ACK（STATUS 仍是 0，原因进 `V_LAST_ERR`） | `src/fee.c:107-125` |
| `0x03` | WRITE | 主→从 | 参数 `ADDR(1) + DATA`；立即写。广播或 quiet（ACK 级别 0）→ 静默；否则 ACK | `src/fee.c:127-146` |
| `0x04` | REG_WRITE | 主→从 | 暂存（≤ `FEE_PEND_MAX = 32` 字节，`src/fee.h:28`），等 `REG_ACTION`；广播/quiet → 静默 | `src/fee.c:148-166` |
| `0x05` | REG_ACTION | 主→从 | 执行暂存写；广播/quiet → 静默 | `src/fee.c:168-177` |
| `0x06` | RECOVERY | 主→从 | **应答，无动作**（本节点没有保护状态可恢复） | `src/fee.c:179-184` |
| `0x08` | REBOOT | 主→从 | **不应答**；50 ms 后软复位。应用与 bootloader 共用 | `src/fee.c:186-193` |
| `0x0A` | RESET | 主→从 | 恢复出厂默认 + 写 Flash；广播/quiet → 静默 | `src/fee.c:195-201` |
| `0x0B` | CAL | 主→从 | 把 2 个 0 字节写到地址 31（中位偏移 OFS），然后 ACK；广播/quiet → 静默 | `src/fee.c:203-214` |
| `0x82` | SYNC_READ | 主→从 | 参数 `ADDR(1) + nLen(1) + ID...`；命中本机 ID 才应答并按下标 k 让槽；`LEN<5` 或 `nLen=0` → 静默；不在列表 → 静默 | `src/fee.c:216-246` |
| `0x83` | SYNC_WRITE | 主→从 | 参数 `ADDR(1) + nLen(1) + (ID + DATA)×N`；命中就写；**永不应答** | `src/fee.c:248-272` |
| 其它（含 `0x09` 参数备份） | — | — | **静默忽略**（既不执行也不应答） | `src/fee.c:274-277` |

**"quiet" 的定义**（ACK 应答级别，寄存器 8，`src/fee.c:22-27,97-100`）：寄存器 8 = 0 时，
除 **PING / READ / SYNC_READ** 之外的指令**照样执行，只是不应答**；= 1（默认，
`src/dev.c:198`）时全部应答。写寄存器 8 本身立即生效（它是镜像里的字节，`ack_level()` 每次
现读）。

### 5.3 Dynamixel 错误位（`src/board.h:389-395`）

| 位 | 值 | 名称 | 本节点是否会产生 |
|---|---|---|---|
| bit7 | `0x80` | Result Fail | **不产生**（没有执行机构） |
| bit6 | `0x40` | Instruction Error（不支持的指令） | 会（`src/dxl2.c:497`） |
| bit5 | `0x20` | CRC / Checksum Error | 会（`src/dxl2.c:200`） |
| bit4 | `0x10` | Range Error | 会（`src/dev.c:733,752`） |
| bit3 | `0x08` | Length Error | 会（`src/dxl2.c:245,250,271,288`） |
| bit2 | `0x04` | Limit Error | **不产生** |
| bit1 | `0x02` | Access Error（写只读区） | 会（`src/dev.c:770`） |

CRC 错误时：若帧的 ID 是本机 ID，回一帧参数为空的 `ERR=0x20` 状态帧；否则静默丢弃
（`src/dxl2.c:196-203`）。

### 5.4 FeeTech 应答 STATUS 字节：恒 0，且**不是**舵机故障字

本节点的 FeeTech ACK `STATUS` 字节**永远是 `0x00`**（`FEE_ST_OK`，`src/fee.c:20,29-35`）。

原因（源码注释，`src/fee.c:15-19`）：真舵机的 STATUS 是**舵机**状态字（过压、编码器、温度、
电流、负载），**飞特工具会把非 0 的 ack 状态当成舵机故障**；本项目自己的主机补丁也曾把
`status != 0` 当整条事务失败。所以：

* 本节点**绝不**在这里报告自己的协议错误；
* 最近一次被拒绝/夹紧的协议错误放在**厂商窗 `V_LAST_ERR`**（DXL 167 / Fee 179，偏移 19，
  `src/board.h:496-500`、`src/dev.c:139`、`src/dev.c:717-723`），主机需要时**主动去读**；
* READ 出错时节点回一个**数据长度为 0 的 ACK**（`src/fee.c:121-123`），主机应把
  "应答数据长度 < 请求长度"当成失败信号，再去问 `V_LAST_ERR`。

`V_LAST_ERR` 里存的是 `DXL_ERR_*`（§5.3）的值。它**会被后续错误覆盖，固件不主动清零**。

---

## 6. 数据面：遥测块

### 6.1 20 字节块（精确布局）

**内容两种协议完全相同**（`src/imu.h:9-20`、`README.md §3`、`host/bus.py:432-467`）：

| 偏移 | 字节 | 内容 | 类型/端序 | 刻度 / 编码 | 出处 |
|---|---|---|---|---|---|
| 0..1 | 2 | 陀螺 X | `int16` LE | **17.5 mdps/LSB**（±500 dps 量程） | `src/board.h:345-346` |
| 2..3 | 2 | 陀螺 Y | `int16` LE | 同上 | 同上 |
| 4..5 | 2 | 陀螺 Z | `int16` LE | 同上 | 同上 |
| 6..7 | 2 | 四元数 X | IEEE 754 **binary16** LE | 见下 | `src/board.h:442` |
| 8..9 | 2 | 四元数 Y | binary16 LE | | |
| 10..11 | 2 | 四元数 Z | binary16 LE | | |
| 12..13 | 2 | 加速度 X | `int16` LE | **0.122 mg/LSB**（±4 g 量程） | `src/board.h:347-348` |
| 14..15 | 2 | 加速度 Y | `int16` LE | 同上 | |
| 16..17 | 2 | 加速度 Z | `int16` LE | 同上 | |
| 18 | 1 | 采样计数 | `uint8`，回绕 | 100 Hz 采样栅格 | `src/board.h:343-344,445` |
| 19 | 1 | 状态位 | 位域 | §6.4 | `src/board.h:446,512-520` |

* **四元数只发 x/y/z**；标量 `w = √(1 − x² − y² − z²)`，**非负**，由主机重建
  （`src/board.h:442`、`src/imu_spi.c:571-577`、`host/bus.py:485-488`）。
* 陀螺 dps = `raw × 0.0175`；加速度 g = `raw × 0.000122`。
* **采样率 100 Hz**（10 ms 栅格，`src/board.h:343-344`、`src/imu.c:49-73`）。
* 主机的控制环通常**只取前 12 字节**（陀螺 + 四元数 xyz），这正是运行时读的长度
  （`TELEM_CTRL_LEN = 12`，`src/board.h:444`；`README.md:102`）。

**坐标系（frame）**：默认上报**芯片系（chip frame）**；厂商窗 `REPORT_FRAME = 1` 时改为上报
**躯干系（trunk frame）**（`src/board.h:485`、`src/imu_spi.c:550-587`、`src/imu_sim.c:167-205`）。
板子的安装关系是 `躯干系 = [+raw_z, +raw_y, −raw_x]`（绕 Y 轴 +90°），对应
`MOUNT = [0.70710678, 0, 0.70710678, 0]`（`src/board.h:331-339`、`host/bus.py:144-150`）。

> **注意（源码不一致，见 §15.6）**：真 SPI 驱动在 `REPORT_FRAME=1` 时只旋转**陀螺和四元数**，
> **加速度保持芯片系**（`src/imu_spi.c:553-594`）；模拟器则把**加速度也一起旋转**
> （`src/imu_sim.c:196-205`）。主机如果消费加速度，不要假定两种构建行为一致。

### 6.2 它在每种协议里的位置

| 协议 | 地址 | 长度 | 内容 | 出处 |
|---|---|---|---|---|
| Dynamixel | **124..143** | **20** | 完整 20 字节块 | `src/board.h:449`、`src/dev.c:696` |
| FeeTech（契约块） | **56..70** | **15** | 12 控制 + 计数 + 状态 + 保留 0 | `src/board.h:450,457-460`、`src/telem_pack.c` |
| FeeTech（诊断别名） | **128..147** | **20** | 完整 20 字节块 | `src/board.h` `FEE_TELEM_NATIVE_ADDR`、`src/dev.c` |

> **本表与下面的块内布局描述的是 native 人格**（`-DFEE_IMU_PERSONALITY=native`；仓库当前
> 默认构建是 ft6）。 FeeTech 侧还有一个编译期的
> **ft6 人格**：它把契约块的计数/状态字节换成 FT6 语义，并把诊断块搬到 124、把上面的
> 128 别名搬到 196。两种人格的完整映射见 **§16**；Dynamixel 侧两种人格完全相同。

**FeeTech 15 字节契约块在 56 处**的精确布局（native 人格，`src/telem_pack.c`）：

| FeeTech 地址 | 契约块内偏移 | 内容 |
|---|---|---|
| 56..57 | 0..1 | 陀螺 X（i16 LE） |
| 58..59 | 2..3 | 陀螺 Y |
| 60..61 | 4..5 | 陀螺 Z |
| 62..63 | 6..7 | 四元数 X（half LE） |
| 64..65 | 8..9 | 四元数 Y |
| 66..67 | 10..11 | 四元数 Z |
| **68** | **12** | 采样计数 `FEE_BLOCK_CNT`（每样本 +1；ft6 人格下是**四元数序号**） |
| **69** | **13** | 状态位 `FEE_BLOCK_STATUS`（ft6 人格下是 **FT6 状态字节**，bit0 极性相反） |
| **70** | **14** | **保留，恒 0** `FEE_BLOCK_RESERVED` |

### 6.3 为什么要有 15 字节契约块（以及主机在混合车队里的规则）

真 HD-1910 在地址 56 起的**文档化块就是 15 字节**：位置/速度/负载/电压/温度/状态/移动/电流；
再往后（71..76）是别的寄存器，不是为外部设备预留的（【实测】`docs/bus_timing_borrow_plan.md §1.2`、
`飞特通讯协议说明.md §13.3`）。

而运行时对**节点和 15 颗舵机用的是同一个 `sync_read`**（地址 56、长度 15），所以：

> **主机在混合车队里必须读 15 字节（地址 56）**，这样一次事务同时拿到节点遥测和全部舵机状态。
> 读 20 字节虽然本机 fw 3.46 的舵机也答应，但每个应答多 5 字节 ⇒ 每台约 +50 µs ⇒ 事务从
> ≈4.9 ms 涨到 ≈5.7 ms，逼近 6 ms 验收线；而且"读超出文档块长"在别的型号/固件上不保证
> （【实测+估算】`docs/bus_timing_borrow_plan.md:46-49,188`）。

因为计数和状态必须塞进这 15 字节，**原始加速度放不下**，所以它只存在于 20 字节诊断块的
别名里（`src/board.h` `FEE_TELEM_NATIVE_ADDR`、`docs/bus_timing_borrow_plan.md §0 D1`）：
native 人格在 128，ft6 人格在 196（§16）。

### 6.4 flags 字节（块偏移 19）的每一位

> **本表描述 native 人格的 flags 字节**（FeeTech 契约块偏移 13 = 地址 69、诊断块偏移 19、
> Dynamixel 块偏移 19 都是它）。**ft6 人格下 FeeTech 契约块偏移 13 不是这个字节**，而是
> FT6 状态字节（bit0 极性相反、bit3 含义不同），见 §16；native flags 字节在 ft6 人格下仍然
> 存在于诊断块 124 的偏移 19 与 196 别名的偏移 19。

| 位 | 值 | 名称 | 含义 | 谁置位 |
|---|---|---|---|---|
| bit0 | `0x01` | `TELEM_FLAG_SFLP_VALID` | **本块携带有效四元数** | 真驱动融合收敛后（`src/imu_spi.c:611-613`）；模拟器有姿态时（`src/imu_sim.c:210-214`） |
| bit1 | `0x02` | `TELEM_FLAG_CNT_WRAP` | 采样计数本轮发生回绕（上一计数 = `0xFF`） | `src/imu_spi.c:617-619`、`src/imu_sim.c:222-224` |
| bit2 | `0x04` | `TELEM_FLAG_GYRO_SAT` | 注入陀螺偏置后计数饱和（clamp 到 ±32767/−32768） | 仅真驱动 SPI 路径（`src/imu_spi.c:535-547`） |
| bit3 | `0x08` | `TELEM_FLAG_SENSOR_ERR` | 传感器不存在/探测失败 | 仅真驱动（`src/imu_spi.c:614-616`） |
| bit4 | `0x10` | `TELEM_FLAG_SIMULATED` | 本块来自模拟器（`IMU_USE_SPI=0`） | 仅模拟器（`src/imu_sim.c:91,103`） |
| bit5 | `0x20` | `TELEM_FLAG_FROZEN` | `SIM_MODE=6 frozen`，每块完全相同 | 仅模拟器（`src/imu_sim.c:91`） |
| bit6 | `0x40` | `TELEM_FLAG_CFG_DIRTY` | 配置未保存 | **当前固件从不置位**（常量在 `src/board.h:519`，`src/` 中无写入点） |
| bit7 | `0x80` | `TELEM_FLAG_FUSION_OK` | **融合算法正在运行**（不是"已收敛"） | 真驱动传感器在线时（`src/imu_spi.c:603-610`）；模拟器（`src/imu_sim.c:103`） |

各位的常量定义见 `src/board.h` `TELEM_FLAG_*`、主机侧同一份表见 `host/bus.py` `TELEM_FLAG_BITS`。
ft6 人格的状态位是**另一张表**（`FEE_ST_*` / `host/bus.py` `FEE_ST_BITS`），不要混用（§16）。

### 6.5 四元数字节全 0 = 融合尚未收敛（主机必须保持上一有效值）

**规则：当 `TELEM_FLAG_SFLP_VALID`（bit0）为 0、且四元数 6 个字节全为 0 时，表示融合还没有
收敛；主机必须沿用自己上一份有效姿态，不能把全 0 当成"单位四元数/静止"。**

* 真驱动：芯片的数据手册给出 SFLP 校准 0.8 s + 姿态稳定 0.7 s ≈ **1.5 s**，固件用
  `LSM_SFLP_CONVERGE_MS = 1500` 主动保持这个窗口：期间**发布零四元数字节**并清 `SFLP_VALID`，
  但 `FUSION_OK` 仍为 1（算法在跑），窗口结束后 flush FIFO 再恢复发布
  （`src/lsm6dsv16x.h:137-145`、`src/imu_spi.c:219-239,603-616`）。
* 【实测】重启后的实际窗口（`docs/bus_timing_borrow_plan.md §7.6`、`README.md:436`）：
  写 `VCMD_RESET_SIM` 后 **9–13 ms** 四元数字节归零；**1.51–1.52 s** 后恢复非零（< 2.5 s）。
* 模拟器：`SIM_MODE=5 sflp-wait` 制造同样的"陀螺正常、四元数全 0"状态，用于验证主机的
  "保持上一有效值"逻辑（`src/imu_sim.h:24`、`README.md:219`）。
* 主机侧参考实现就是这么做的：`host/bus.py:535-541` 只在 `quat_valid` 时更新 `last_quat`。

> 主机不要用全 0 四元数去重建 `w=1`：那样会把"没有姿态"误判成"姿态为单位四元数"，
> 得到一串假的零角速度姿态。`FUSION_OK` 与 `SFLP_VALID` 的组合才是判据
> （`src/imu_spi.c:603-607`）。

### 6.6 真传感器的合理性校验值（主机解码器的自检基线）

以下都是【实测】真 PCBA + 真 LSM6DSV16X 的静止表征（`docs/bus_timing_borrow_plan.md §7.6`、
`README.md:427-439`；同一组数字可以用 `host/tools/sensor_probe.py` 复现，
`--json` 会把它写成机器可读的探针报告）：

| 项目 | 实测值 |
|---|---|
| 四元数范数（模长） | **1.0000**（探针 300/300，min = max = 1.0） |
| 静止加速度模长 | **996–997 mg**（300 样本均值 997.4 mg） |
| 四元数重力方向 vs 加速度方向 | **0.05–0.12°**（mean 0.058°，max 0.115°，n=300） |
| 陀螺零偏（原始计数，静止） | x = −55.7、y = +9.2、z = +41.8 counts → **x = −0.97 / y = +0.16 / z = +0.73 dps** |
| 陀螺每轴噪声 std | **0.017–0.031 dps**（x 0.029 / y 0.030 / z 0.017） |
| 补偿它的厂商值 `gyro_bias` | **(+56, −9, −42) raw counts**（固件把它**加**到陀螺原始计数上，`src/imu_spi.c:532-543`） |

传感器本体：`WHO_AM_I = 0x70`，SPI0 mode 0 @ 7.5 MHz，陀螺 ±500 dps @ 120 Hz 高性能，
加速度 ±4 g @ 120 Hz，SFLP game rotation vector @ 120 Hz（`docs/bus_timing_borrow_plan.md §7.6`、
`src/lsm6dsv16x.h:68-75`）。**这些是传感器/驱动的表征值，不是协议保证**；换个安装或标定就会变。

### 6.7 其它可读字段

| 字段 | 协议/地址 | 值 | 出处 |
|---|---|---|---|
| 实时 tick | Dynamixel **120..121**（u16 LE） | `systick_get_ms() & 0xFFFF`，自由于运行、回绕 | `src/dev.c:686-687` |
| 电压 | Dynamixel **144..145**（u16 LE） | **恒 0**：本节点没有电池分压，"报 0 而不是假值"是设计选择——`microduck` 的电压平均会过滤 0，不会把假读数算进去 | `src/dev.c:699-702`、`docs/dynamixel_slave.md:136` |
| 温度 | Dynamixel **146**（u8，°C） | 片内温度传感器（ADC0 通道 16），1 Hz 更新，clamp 0..125；`TEMP_SENSOR_ENABLE=0` 时固定 30 | `src/dev.c:527-586,703`、`src/board.h:87-91` |
| 实时 tick / 电压 / 温度（FeeTech） | — | **没有独立暴露**：FeeTech 62/63 落在契约块内（= 四元数 X 的 two bytes），不是电压/温度。FeeTech 侧没有温度寄存器 | `src/board.h:450,457-460`、`src/dev.c:642-652` |
| 硬件错误状态 | Dynamixel **70..71**（RO） | 0；`CLEAR(0x10)` 清零 | `src/dev.c:631,823-851` |

---

## 7. 寄存器 / 内存映射

节点为**每种协议各维护一份 256 字节寄存器镜像**（`REG_SPACE_SIZE = 256`，`src/board.h:441`），
Dynamixel 用 XL330 控制表布局、FeeTech 用 HLS 内存表布局（`src/dev.h:1-18`）。读发生在
中断里、直接读镜像；镜像由主循环发布（`dev_refresh()`，`src/dev.c:659-712`、`src/main.c:264-278`）。

### 7.1 Dynamixel 控制表（主机可能碰的地址）

| 地址 | 名称 | 取值（出厂默认） | R/W | 出处 |
|---|---|---|---|---|
| 0..1 | Model Number | **1200（`0x04B0`，XL330）** | 只读 | `src/board.h:322`、`src/dev.c:153` |
| 6 | Firmware Version | **`0x10`（v1.0）** | 只读 | `src/board.h:53`、`src/dev.c:154` |
| 7 | ID | 200（clamp 1..252，持久化） | 读写 | `src/dev.c:155,307-312` |
| 8 | Baud Rate | 3 = 1 Mbps（码 0..6） | 读写 | `src/dev.c:156,313-318` |
| 9 | Return Delay Time | 0 | 读写（无作用） | `src/dev.c:157` |
| 10 / 11 / 12 / 13 | Drive Mode / Operating Mode / Secondary ID / Protocol Type | 0 / 3 / 255 / 2 | 读写 | `src/dev.c:158-161` |
| 20..23 | Homing Offset | 0 | 读写 | `src/dev.c:162` |
| 24..27 | Moving Threshold | 10 | 读写 | `src/dev.c:163` |
| 31 | Temperature Limit | 70 | 读写 | `src/dev.c:164` |
| 32..33 / 34..35 | Max / Min Voltage Limit | 70 / 35 | 读写 | `src/dev.c:165-166` |
| 36..37 / 38..39 | PWM / Current Limit | 885 / 1750 | 读写 | `src/dev.c:167-168` |
| 44..47 / 48..51 / 52..55 | Velocity / Max Position / Min Position Limit | 445 / 4095 / 0 | 读写 | `src/dev.c:169-171` |
| 60 / 62 / 63 | Startup Config / PWM Slope / Shutdown | 0 / 140 / 53 | 读写 | `src/dev.c:172-174` |
| 64 | Torque Enable | 0 | 读写（**无执行机构**） | `src/dev.c:175` |
| 68 | Status Return Level | 2 | 读写 | `src/dev.c:176` |
| 69 | Registered Instruction | 0 | **只读** | `src/dev.c:631` |
| 70..71 | Hardware Error Status | 0 | **只读** | `src/dev.c:632` |
| 76..90 | 速度/位置/电流环增益 | 1600 / 180 / 0 / 0 / 400 … | 读写（无作用） | `src/dev.c:177-181` |
| 100..119 | Goal 系列 | 0 | 读写（无作用） | `memset`，`src/dev.c:149` |
| 120..121 | **Realtime Tick** | 实时 ms 低 16 位 | **只读** | `src/dev.c:633,687` |
| 122 / 123 | Moving / Moving Status | 0 | **只读** | `src/dev.c:633` |
| **124..143** | **IMU 遥测块（20 字节）** | §6 | **只读** | `src/dev.c:634,696` |
| 144..145 | Present Input Voltage | **0** | **只读** | `src/dev.c:634,702` |
| 146 | Present Temperature | 片内温度 | **只读** | `src/dev.c:634,703` |
| 147 | Backup Ready | 0 | **只读** | `src/dev.c:634` |
| **148..167** | **厂商配置窗（20 字节）** | §8 | 读写 | `src/board.h:471`、`src/dev.c:638` |
| 168..179 | Indirect Address 前 12 字节（默认值 224..251） | 读写 | 无间接寻址语义；**180 起被身份窗/升级窗覆盖**（见下） | `src/dev.c:182-184`、`src/dev.c:622-624`、`docs/dynamixel_slave.md:158` |
| **180..195** | **身份窗（两种协议同址）** | §9 | **只读** | `src/dev.c:622-624,706` |
| 196..207 | 0 | **只读** | 落在 `ro_high()`（`a >= 180`）里 | `src/dev.c:622-624` |
| **208..255** | 升级会话窗（仅 bootloader 消费） | §10 | 应用态**拒绝写**；与 XL330 的 Indirect Address/Data 区间重叠 | `src/dev.c:622-624`、`src/boot_regs.c:219-226` |

**Dynamixel 只读范围**（写整帧会因碰到只读字节而**整帧**被拒 `ERR=0x02`，`src/dev.c:630-640,762-774`）：
`0..6`、`69`、`70..71`、`120..123`、`124..147`、`180..255`。

**数据手册初始值的对照**见 `docs/dynamixel_slave.md §3.1`（1600/180/0/0/400/0/0、885、1750、
445、4095、0、140、53 等），与 `src/dev.c:167-181` 一致。

### 7.2 FeeTech HLS 内存表（主机可能碰的地址）

| 地址 | 名称 | 取值（出厂默认） | R/W | 出处 |
|---|---|---|---|---|
| 0 / 1 | 固件主/次版本 | **1 / 0** | **只读** | `src/dev.c:190-191` |
| 3..4 | 型号（LE） | **`0x4D49`（'I','M'）** | **只读** | `src/board.h:329`、`src/dev.c:192` |
| 5 | ID | 200（clamp 0..252，持久化） | 读写 | `src/dev.c:193,320-325` |
| 6 | 波特率码 | 0 = 1 Mbps（码 0..11） | 读写 | `src/dev.c:194,326-331` |
| 7 | 副 ID | 254（关闭） | 读写（无作用） | `src/dev.c:195` |
| 8 | **应答状态级别** | **1** | 读写 | `src/dev.c:198`、`src/fee.c:22-27` |
| 9..10 / 11..12 | 最小 / 最大角度限制 | 0 / 4095 | 读写（无执行机构） | `src/dev.c:199-200` |
| 31..32 | OFS（中位偏移） | 0 | 读写；`CAL(0x0B)` 会写 0 | `src/dev.c:201`、`src/fee.c:203-209` |
| 33 | 运行模式 | 0（位置伺服） | 读写（无作用） | `src/dev.c:202` |
| 40 | 扭矩开关 | 0 | 读写（**无执行机构**） | `memset`，`src/dev.c:149` |
| 42 / 44 / 46 / 48 | 目标位置 / 目标电流 / 运行速度 / 转矩限制 | 0 | 读写（无作用） | `memset` |
| 50 / 51 / 52 | Kp / Kd / Ki（RAM） | 0 | 读写（无作用） | `memset` |
| **55** | **锁标志** | **0**（手册初始值是 1，本节点有意改成 0） | 读写 | `src/dev.c:203-207` |
| **56..70** | **15 字节契约块** | §6.2 | **只读** | `src/dev.c:647,695` |
| **128..147** | **20 字节诊断块** | §6.1 | **只读** | `src/dev.c:648,697` |
| **160..179** | **厂商配置窗（20 字节）** | §8 | 读写 | `src/board.h:472`、`src/dev.c:649-650` |
| **180..195** | **身份窗** | §9 | "只读"（见 §7.4） | `src/dev.c:623` |
| 208..255 | 升级会话窗 | §10 | 应用态：**接受但忽略**（见 §7.4） | `src/dev.c:645-652` |

**FeeTech 只读范围**（`ro_fee`，`src/dev.c:642-652`）：`0..1`、`3..4`、`56..70`、`128..147`、
`180..255`。但 FeeTech 的"只读"语义与 Dynamixel **不同**，见下。

### 7.3 锁标志（FeeTech 寄存器 55）的精确语义

【源码】`src/dev.c:754-760`：当 `55 != 0` 且写入地址 `< 40` 时，写入**仍然进入 RAM 镜像并
立即生效**，只是**不标记为需要持久化**（掉电后回到 EEPROM/默认值）。它的手册语义是
"EPROM 写入是否掉电保存"，**不是"是否允许写"**（`飞特通讯协议说明.md §10.3.1, §5.3`）。

本节点的默认值是 **0（可持久化）**，与手册初始值 1 不同，是**有意的偏差**，这样主机改 ID/
波特率后能直接存下来（`src/dev.c:203-207`）。

### 7.4 两种映射的对应关系，以及"写只读区"的差异

| 语义 | Dynamixel 地址 | FeeTech 地址 |
|---|---|---|
| 型号 / 固件版本 | 0..1 / 6 | 3..4 / 0..1 |
| ID / 波特率 | 7 / 8 | 5 / 6 |
| 遥测（20 字节诊断块） | 124..143 | 128..147（别名） |
| 遥测（15 字节契约块） | —（DXL 无 15 字节形态） | 56..70 |
| 厂商配置窗 | 148..167 | 160..179 |
| 身份窗 | 180..195 | 180..195（同址） |
| 升级会话窗 | 208..255 | 208..255（同址） |

**写只读区的差异（主机必须知道）**【源码】`src/dev.c:762-792`：

* **Dynamixel：整帧拒绝**。写操作只要有一个字节落在只读范围，**整个写被拒绝**并返回
  `ERR=0x02`（ACCESS）。所以 DXL 下写身份窗/升级窗会得到明确的 ACCESS 错误——这正是
  节点提示主机"先进入 boot 模式"的方式（`src/dev.c:618-621`）。
* **FeeTech：接受但忽略**。只读字节被跳过检查、其余字节仍写入镜像；随后主循环发布时会把
  只读字段（遥测、身份窗等）用真实值覆盖。**因此 FeeTech 下写身份窗或升级窗不会报错，
  而是"静默无效"**——一个主机错误地以为"写 208 就已经开始升级"时会毫无提示。
  （`src/dev.c:772` 的 `continue`。）

---

## 8. 厂商配置窗口

### 8.1 完整 20 字节布局

两种协议的窗口**同一张表**，只是基址不同：Dynamixel **148**、FeeTech **160**（`src/board.h:470-472`）。
偏移常量见 `src/board.h:476-500`，填充逻辑见 `src/dev.c:104-142`（`vendor_sync()`），
解析逻辑见 `src/dev.c:213-299`（`vendor_apply()`）。

| 偏移 | 名称 | 字节 | R/W | 含义 / 取值 | 出处 |
|---|---|---|---|---|---|
| 0..1 | `MAGIC` | 2 | r/w | **`0x4D49`（'I','M'，LE）**；`vendor_apply()` 只在 magic 正确时才处理命令 | `src/board.h:474,477-478`；`src/dev.c:221-223` |
| 2 | `CMD` | 1 | w | 命令码（§8.3）；执行后由节点清 0，读回恒 0 | `src/board.h:479`；`src/dev.c:268-270` |
| 3 | `SIM_MODE` | 1 | r/w | 模拟模式 0..6（仅 `IMU_USE_SPI=0` 构建改变数据源；真驱动下会触发 `imu_restart()`） | `src/board.h:480`；`src/dev.c:225-231` |
| 4..5 | `SIM_AMP` | 2 | r/w | 幅度千分比；**写值被夹到 100..5000** | `src/board.h:481-482`；`src/dev.c:232-235` |
| 6..7 | `SIM_FREQ` | 2 | r/w | 频率千分比；**写值被夹到 100..5000** | `src/board.h:483-484`；`src/dev.c:237-240` |
| 8 | `REPORT_FRAME` | 1 | r/w | 0 = 芯片系（默认）/ 1 = 躯干系；非法值忽略 | `src/board.h:485`；`src/dev.c:242-246` |
| 9 | `PROTO_LOCK` | 1 | r/w | 0 = 自动 / 1 = 仅 Dynamixel / 2 = 仅 FeeTech；`> 2` 忽略 | `src/board.h:486`；`src/dev.c:247-250` |
| 10..11 | `GYRO_BIAS_X` | 2 | r/w | `int16`；**直接加到上报的陀螺原始计数上** | `src/board.h:487-488`；`src/imu_spi.c:532-543` |
| 12..13 | `GYRO_BIAS_Y` | 2 | r/w | 同上 | `src/board.h:489-490` |
| 14..15 | `GYRO_BIAS_Z` | 2 | r/w | 同上 | `src/board.h:491-492` |
| 16 | `MIRROR_BAUD` | 1 | r/w | 镜像/调试口波特率码（FeeTech 编码表）；非法忽略 | `src/board.h:493`；`src/dev.c:258-262` |
| 17 | `DBG_LEVEL` | 1 | r/w | 0 关 / 1 仅错误 / 2 启动+周期统计（默认）/ 3 每帧跟踪；`> 3` 忽略 | `src/board.h:494`；`src/dev.c:263-266` |
| 18 | `STATUS` | 1 | r | 状态位（§8.5）；**写入被接受但被忽略** | `src/board.h:495`；`src/dev.c:138` |
| 19 | `LAST_ERR` | 1 | r | 最近一次被拒绝/夹紧的协议错误（`DXL_ERR_*`）；**写入被接受但被忽略** | `src/board.h:496-500`；`src/dev.c:139,717-723` |

### 8.2 读写规则（重要）

* **可写字段**：偏移 0..17（含 magic）可写；`STATUS`(18) 与 `LAST_ERR`(19) 可写但被忽略，
  节点每次发布都用真实状态覆盖（`src/dev.c:135-141,635-638`）。为什么不让它们只读：主机
  习惯**一次写整 20 字节窗口**，如果拒绝会让可用字段一起写不进去（`src/dev.c:635-638`、
  `docs/dynamixel_slave.md:146-148`）。
* **命令执行需要 magic**：`vendor_apply()` 先读窗口 magic，不等于 `0x4D49` 就直接
  return（`src/dev.c:221-223`）。实践中窗口里本来就存着 magic，所以**单独写偏移 2 一个字节
  也能执行命令**；但稳妥的做法是**读回整窗 → 改字段 → 整窗写回**（`host/upgrade.py:457-460,428-431`
  的 `ask_for_boot()` / `confirm_image()` 就是这么做的）。
* **命令执行时机**：写入落在窗口内（`addr+len` 与 `[base, base+19]` 相交）时，
  `dev_write()` 末尾调用 `vendor_apply()`（`src/dev.c:782-790`）。命令被消费后节点把 `CMD`
  清 0，所以**读窗口永远读到 `CMD=0`**（`src/dev.c:268-270`、`src/dev.c:140`）。
* **写窗口不会被"整帧拒绝"波及**：Dynamixel 的 `ro_dxl()` 特意**不**把 148..167 视为只读
  （`src/dev.c:635-638`），所以 20 字节整窗写入不会被 ACCESS 拒绝。
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

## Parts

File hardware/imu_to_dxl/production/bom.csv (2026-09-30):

Designator | Footprint | Quantity | Value | LCSC Part #
C1 | C0402 | 1 | 100p | C106200
C10, C11, C17 | C0402 | 3 | 27pF/50V | C107002
C12, C13, C14, C15, C16, C18, C19, C2, C7, C8, C9 | C0402 | 11 | 100nF/16V | C1525
C20, C21 | C0402 | 2 | 1uF/10V | C106254
C22 | C0402 | 1 | 1nF/50V | C106205
C5 | C0603 | 1 | 22uF/6.3V | C59461
C6 | C0805 | 1 | 10uF/50V | C2932476
D1 | SMA_L4.4-W2.6-LS5.0-RD | 1 | SMAJ24A | C90510
D2 | SOD-323_L1.7-W1.3-LS2.5-BI | 1 | 3.3V ESD | C46551335
F1 | F0603 | 1 | PTC(40R) | C2687114
L1 | IND-SMD_L3.0-W3.0_SWPA3010S | 1 | 10uH/920mA | C45403
Q1 | SOT-23 | 1 | MMBT3906 | C727128
R1 | R0402 | 1 | 75K | C144737
R10, R11, R12, R13, R17, R18, R2, R21, R22, R23, R24, R25, R26 | R0402 | 13 | 51R | C137960
R14 | R0402 | 1 | 1K | C11702
R15, R16, R19, R27, R28, R30, R7, R8 | R0402 | 8 | 10K | C25744
R29 | R0402 | 1 | 20k | C25765
R3, R31 | R0402 | 2 | 100K | C25741
R32, R9 | R0402 | 2 | 0R | C60485
R4 | R0402 | 1 | 30K | C25776
R5 | R0603 | 1 | 51R | C2907181
R6 | R0402 | 1 | 24K | C138026
U1 | SOT-23-6_L2.9-W1.6-P0.95-LS2.8-BR | 1 | ETA2845S2G_C22362741 | C22362741
U2 | LQFP-48_L7.0-W7.0-P0.50-LS9.0-BL | 1 | GD32F303CCT6 | C116151
U3 | LGA-14_L3.0-W2.5-P0.50-BR | 1 | LSM6DSV16XTR | C5267406
U4 | SOT-23-5 | 1 | SN74LVC1G126DBVR | C46472327
U5 | SOT-23-5 | 1 | SN74LVC1G125DBV | C3040625
U6 | SOT-23-5_L3.0-W1.7-P0.95-LS2.8-BR | 1 | ME6211C18M5G-N | C236671
X1 | CRYSTAL-SMD_4P-L3.2-W2.5-BL | 1 | XL2EL89CSI-111YLC-12M | C5280576

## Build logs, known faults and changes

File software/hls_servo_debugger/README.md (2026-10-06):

# HLS 舵机浏览器调试工具

这是一个面向飞特 HLS 系列串行总线舵机的浏览器调试软件，放在
`microduck-community-kit/software/hls_servo_debugger` 下。后端使用 Python + Flask + pyserial，
前端为纯 HTML/CSS/JavaScript，无需前端构建工具。

工具以 `FTServo_Linux-main/src/HLSCL.cpp`、`SCS.cpp` 和官方
《磁编码 HLS 舵机-内存表解析》为依据，覆盖 HLS 舵机的指令、内存表、控制模式、
同步读写和原始协议调试。

## 功能范围

- 串口连接：`/dev/ttyACM1` 等设备选择、常用波特率、超时设置、自动探测 ID1。
- **整机 15 台舵机初始化**：按 microduck 的关节表逐个把出厂舵机（ID 1）编号成
  20~24 / 30~34 / 10~14，并按选择的工艺做初始位置校准、回读校验和写入锁保护；
  15 台列表按 ID 升序显示，点检后在线的点黄、本页已完成的显示绿；
  另有 9/11 号多圈开关（默认关闭）、19 号电压/过流保护开关（默认关闭）。
  见下文《整机 15 台舵机初始化》。
- PING / 扫描：单个 Ping、按 ID 范围扫描、可读取版本。
- 实时反馈：一次读取 56~70 共 15 字节，显示位置/速度/负载/电压/温度/状态/移动/目标位置/电流，并绘制趋势图。
- 位置控制：位置伺服模式、扭矩开关、目标位置、速度、加速度、目标电流、转矩限制、角度限制、异步写（REG_WRITE）+ REG_ACTION、中位校准（可选 CAL 后保存到 EPROM 并重新上锁）。
- 速度/电流/PWM：恒速模式、恒流模式、PWM 开环模式，以及对应写入方法。
- 参数配置：按 HLS 内存表自动生成 0~86 字段的读取/写入界面，支持枚举、位域、正负号字段编码；
  回读值列只显示可读懂的结果（计数 + 工程量 / 枚举名 / 打开的位名），原始字节放在悬停提示里。
- 同步读写：SYNC_READ(0x82)、SYNC_WRITE(0x83)、同步位置写、同步速度写。
- 高级调试：任意地址/长度 READ/WRITE、REG_WRITE、REG_ACTION、RESET、RECOVERY、CAL、写锁控制、原始十六进制帧收发。
- 日志：显示 TX/RX/错误帧，便于核对校验和和异常。
- 内存表参考：完整字段、地址、范围、单位、方向位说明。

HLS 参考库中的 `WritePosEx`、`RegWritePosEx`、`SyncWritePosEx`、
`SyncWriteSpe`、`ServoMode`、`WheelMode`、`EleMode`、`WriteSpe`、
`WriteEle`、`EnableTorque`、`unLockEprom`、`LockEprom`、
`CalibrationOfs`、`FeedBack`、`ReadPos/ReadSpeed/...` 均有对应前端操作或
API 入口。

## 目录结构

```text
hls_servo_debugger/
├── pyproject.toml
├── README.md
├── run.sh
├── hls_debugger/
│   ├── __init__.py
│   ├── __main__.py
│   ├── protocol.py        # FT-SCS/HLS 协议、串口收发、同步读写、应用层指令
│   ├── memory_table.py    # HLS 内存表、数据编解码、反馈解码
│   ├── provision.py       # microduck 15 个关节表 + 初始化（编号/校准）流程
│   ├── server.py          # Flask API 和 Web 服务入口
│   └── selftest.py        # 无硬件协议自检（含从站模拟，可离线跑完整初始化流程）
│   └── static/
│       ├── index.html
│       ├── style.css
│       └── app.js
├── hw_test.py             # 真机只读连通性测试（PING/READ，不产生动作）
└── .venv/                 # uv 创建的虚拟环境（本地生成）
```

## 安装与运行

### 方式一：使用 `run.sh`

```bash
cd microduck-community-kit/software/hls_servo_debugger
./run.sh
```

脚本会自动用 `uv` 创建 `.venv` 并安装 Flask、pyserial，然后启动服务。

### 方式二：手动使用 uv

```bash
cd microduck-community-kit/software/hls_servo_debugger

uv venv .venv --python python3
uv pip install 'Flask>=2.2,<3.0' 'pyserial>=3.5'

uv python -m hls_debugger
```

启动后浏览器访问：

```text
http://127.0.0.1:8765/
```

默认会自动打开浏览器；使用 `--no-browser` 可禁止自动打开：

```bash
.venv/bin/python -m hls_debugger --no-browser --port 8765
```

### 方式三：直接跑在机器鸭核心板上（推荐，见下文《部署到核心板》）

核心板上没有 `uv`，依赖用 apt 装（`python3-flask` / `python3-serial`），
`run.sh` 会自动退回系统 Python，并把默认串口设成 `/dev/ttyS2`：

```bash
ssh root@<板子> 'cd /opt/hls_servo_debugger && ./run.sh --host 0.0.0.0'
```

然后在同一局域网的电脑上开 `http://<板子IP>:8765/`。

## 部署到核心板（radxa-zero3）

这块板子的事实（2026-10-05 实测）：`root@192.168.124.4`、Armbian 26.8.1（Ubuntu 26.04）、
**Python 3.14**、**没有 `uv` 也没有 `pip`**、apt 能连上 `ports.ubuntu.com`；
舵机与 `imu_to_dxl` 小板共用 **`/dev/ttyS2`**（`/etc/robot/robotd.toml` 的 `bus.port`），
平时由 `robotd` 持有。

```bash
# 1) 依赖：用发行版的包，不碰 pip（板子上没有，也没有 PyPI 直连）
ssh root@<板子> 'apt-get update && apt-get install -y python3-flask python3-serial'
ssh root@<板子> 'python3 -c "import flask, serial; print(flask.__version__, serial.__version__)"'

# 2) 拷源码（.venv 是本机的 x86_64 环境，不要拷）
rsync -av --delete --exclude '.venv' --exclude '__pycache__' \
      software/hls_servo_debugger/ root@<板子>:/opt/hls_servo_debugger/

# 3) 用的时候手动起（前台跑，Ctrl-C 就停；没有 systemd 单元，也别做成开机自启）
ssh root@<板子> 'systemctl stop robotd'                    # 让出总线
ssh root@<板子> 'cd /opt/hls_servo_debugger && ./run.sh --host 0.0.0.0 --no-browser'
#    浏览器开 http://192.168.124.4:8765/  →「连接与扫描」选 /dev/ttyS2、1 Mbps →「点检 15 台」
# 4) 用完了：Ctrl-C 停掉它，再把总线还给 robotd
ssh root@<板子> 'systemctl start robotd'
```

**它故意不做成系统服务。**这是台面/标定用的工具，用完就该关：它和 robotd 抢同一根串口，
常开着只会制造"两个进程互吃应答帧"的机会。想让它在你退出 SSH 后继续跑就用 `tmux`/`nohup`，
但记住用完要收掉。

几条要注意的：

* **停 `robotd` 不会切扭矩**，机器人保持当前姿态；但这时没有任何人在平衡，别在它站着的时候
  去拧关节。
* **一次只让一个进程持有串口。** `robotd` 的 `TIOCEXCL` **拦不住 root**（实测：两个 root 进程
  能同时打开 `/dev/ttyS2`），所以本工具在连接前会扫 `/proc/<pid>/fd`，发现别人占着就返回
  `409 port_busy` 并点名（`robotd (pid 975)`）。`fuser -v /dev/ttyS2` 也能看是谁拿着。
* `--host 0.0.0.0`：**任何能连到板子的人都能给舵机写寄存器**，只在可信任的局域网里开。
* 自检（不需要硬件，也不需要 robotd 停）：`ssh root@<板子> 'cd /opt/hls_servo_debugger && python3 -m hls_debugger.selftest'`
  ——板子上没有 Rust 源码，与 `feetech.rs` 对拍的那条用例会自动跳过。

## 快速上手

1. 给舵机接好电源和串口总线，确认设备确实是 `/dev/ttyACM1`（核心板上是 `/dev/ttyS2`）。
2. 打开页面，在“连接与扫描”中选择串口，波特率先选 `1000000`，点击“连接”。
3. 点击“Ping”确认 ID 1 是否在线。若失败，依次尝试 115200、500000、250000、57600、38400，或使用“自动探测 ID1”。
4. 点开“实时反馈”，点击“读取一次/开始轮询”，观察位置、速度、电压、温度、电流。
5. 点开“位置控制”，先“打开扭矩”，确认机械安全后写目标位置。
   初次测试建议：
   - 目标位置：`2048`（约 180°）或接近当前位置；
   - 速度：`60`（约 43.9 RPM）；
   - 加速度：`10~30`；
   - 目标电流：从 `200`（约 1.3 A）左右开始，根据负载调整。
6. 修改 ID、波特率、角度限制等 EPROM 参数前，建议先关闭扭矩，必要时关闭写入锁。
   修改 ID 后需要重新连接/扫描新 ID；修改波特率后需要重新连接新波特率。
7. 整机装配时，用“舵机初始化”页签给 15 台新舵机编号并做初始位置校准，见下一节。

## 整机 15 台舵机初始化

microduck 有 15 个关节，新舵机出厂都是 **ID 1 / 1 Mbps**，需要逐个改成对应的关节 ID。
“舵机初始化”页签把这套流程做成了向导：**一次接一个新舵机**，改完一颗拔下来换下一颗。

### 关节表（来自机器人软件，不是本工具自造的）

关节角零点在 **2048 计数**上、**方向 = −1**，与 `microduck_feetech` 的驱动层一致
（`duck-control/src/feetech.rs` 的 `POSITION_CENTER` / `POSITION_DIRECTION`）：

```text
关节角 = DIRECTION · (计数 − 2048) · 2π/4096        DIRECTION = −1（实测）
计数   = 2048 + DIRECTION · 关节角/0.0879°          都在 0..4095 内
```

位置字段是干净的 **0..4095**、没有负值、没有方向位。**方向是实测值，不是继承值**：
XL330 那一代是 `+1`，HD-1910-C001 在同样的舵盘安装下转向相反（2026-10-03 手转三个关节，
`microduck_feetech/docs/robot/joint-direction-check.md`）。所以下表给两个数：

- **关节角计数** = `DEFAULT_POSITION` 换算出来的角度（可负，left_hip_pitch = −299）；
- **舵机字段** = 要写进 42/56 号寄存器的值 = `2048 + 方向 × 关节角计数`
  （方向 −1 时 left_hip_pitch = **2347**，负角在字段里表现为 2048 **以上**的计数）。

> **2026-10-05 更正。** 本页与工具在 2026-10-03 方向翻转之前写的是 `rad = +(计数 − 2048)·…`、
> 「舵机字段 = 2048 + 关节角计数」，那一列**整列是镜像的**（left_hip_pitch 曾写 1749）。
> 照旧表把关节摆过去，15 个关节会全部对到镜像位置；`POSITION_DIRECTION` 现在是唯一的
> 符号来源，`hls_debugger/selftest.py` 有一条用例直接读 `feetech.rs` 核对它。

| 部位 | 关节名 | ID | home 姿态 | 关节角计数 | 舵机字段（2048 − 角） |
|---|---|---|---|---|---|
| 左腿 | left_hip_yaw | 20 | 0.000° | 0 | **2048** |
| 左腿 | left_hip_roll | 21 | −5.002° | −57 | **2105** |
| 左腿 | left_hip_pitch | 22 | −26.236° | −299 | **2347** |
| 左腿 | left_knee | 23 | −0.281° | −3 | **2051** |
| 左腿 | left_ankle | 24 | 25.955° | 295 | **1753** |
| 头颈 | neck_pitch | 30 | 20.002° | 228 | **1820** |
| 头颈 | head_pitch | 31 | 20.002° | 228 | **1820** |
| 头颈 | head_yaw | 32 | 0.000° | 0 | **2048** |
| 头颈 | head_roll | 33 | 0.000° | 0 | **2048** |
| 头颈 | mouth | 34 | 0.000° | 0 | **2048** |
| 右腿 | right_hip_yaw | 10 | 0.000° | 0 | **2048** |
| 右腿 | right_hip_roll | 11 | 5.002° | 57 | **1991** |
| 右腿 | right_hip_pitch | 12 | 26.236° | 299 | **1749** |
| 右腿 | right_knee | 13 | 0.281° | 3 | **2045** |
| 右腿 | right_ankle | 14 | −25.955° | −295 | **2343** |

> 2048 是**关节角 0**，不是 home 姿态。两者相差上表两列之差：例如 left_hip_pitch 站在 home
> 姿态时读数应该是 **2347**，而"关节角 0"读 2048。整机装舵盘时别把这两个混起来。

这张表抄自 `microduck_feetech`（官方 microduck 的飞特舵机适配版）：

- `duck-control/src/model.rs`：`JOINT_IDS`（15 个总线 ID）、`DEFAULT_POSITION`（home 姿态角）、
  `FACTORY_ID = 1`、`EXPECTED_BAUD_CODE = 0`、`IMU_DXL_ID = 200`；
- `duck-ipc-proto/src/lib.rs`：`JOINT_NAMES`（关节名，顺序与 ID 表一一对应）。

`model.rs` 里那几条常量顺带钉死了本工具依赖的两个前提：**ID 1 与 200 都不属于任何关节**，
所以“总线上出现 ID 1”就等于“有一颗还没编号的新舵机”；新舵机出厂就在 1 Mbps，
不需要换波特率去找它。`selftest.py` 里有一条用例把这张表与 model.rs 的期望值逐项对齐，
改动机器人软件时它会先失败，而不是让工具悄悄用错表。

### 初始化一台舵机做了什么

1. **预检**：ID 1 必须在线；目标 ID 必须没有应答（已在线的关节会被拒绝，避免重复 ID）；
   顺便报告总线上还有哪些关节、有没有 IMU 节点。
2. **关闭扭矩**（40 号 = 0），厂商的 `unLockEprom()` 也是这个顺序。
3. **关闭写入锁**（55 号写 0，EPROM 写入掉电保存）→ **写主 ID**（5 号）→ 写完后
   舵机就开始用新 ID 应答，所以上锁也要发给新 ID。
4. **写波特率**（6 号 = 0，1 Mbps）与**应答状态级别**（8 号 = 1，保证后续指令都有应答）。
5. **9/11 号角度限制**：勾选「打开多圈绝对位置控制」写 **0/0**（多圈，取消固件行程限制），
   不勾选写 **0/4095**（单圈行程）。这个开关**两个方向都会真的写寄存器**——
   「关闭」是把 0/4095 写回去，不是跳过不写，所以对一台已经开过多圈的舵机同样有效。
   **界面默认关闭**（台面单机调试一圈内更安全）；整机装配必须打开，见下面《真机实测》。
6. **19 号卸载条件**（EPROM 位域，见 `memory_table.PROTECT_BITS`）：BIT0 电压保护、
   BIT1 磁编码、BIT2 过热、BIT3 过流保护，置 1 表示**触发时舵机卸载**（不再输出扭矩）。
   界面上有两个选项（电压 / 过流），**默认都不打开**——关节中途卸力就是摔倒，
   这个取舍交给人来定。工具按**读改写**只动 BIT0/BIT3，BIT1/BIT2 保持舵机原值。
7. **写位置环增益**：EEPROM **21/22**（掉电保存，上电加载进 RAM）与 RAM **50/51**
   （立即生效）。默认 **Kp = 32、Kd = 0**，两个都能在界面上改。
   **不要用 `robotd` 那份默认的 200**：那是给 XL330 的 0..16383 标度调的，在飞特
   0..254 上是顶格，实测会让关节自激振荡（5 A、74 °C）。`Kd` 写 0 是为了与
   `duck-control` 的 `set_gain` 对齐——robotd 接管后会用 `robotd.toml` 的 `gain`
   覆盖 RAM 50，所以**两边要一致**，见下面《真机实测》。
8. **初始位置校准**（按下面选的方式）。
9. **打开写入锁**（55 号写 1，EPROM 掉电不保存），再回读 ID / 波特率 / 锁 / 模式 /
   角度限制（按上面的选择校验单圈 0/4095 或多圈 0/0）/ **19 号卸载条件** /
   位置偏移 / 15 字节反馈做校验。
10. 结束时关闭扭矩，并提示断电、拔下、换下一颗。

写入锁的措辞容易记反，按厂商内存表的字面意思：**写 0 = 关闭写入锁**（能改 ID/波特率，
掉电保存），**写 1 = 打开写入锁**（掉电不保存）。所以“解锁”是写 0，“上锁”是写 1。

#### 还有一条：56 号位置读数必须在单圈 0..4095 里（2026-10-05 加）

出厂 **18 号相位 = 0x34**（bit 4「角度反馈模式 = 全角度」，15 个舵机完全一致，真机实测）
时，位置读数**不会自己回绕**：关节被手推过一整圈之后 56 号会读到 4096 以上。`robotd`
的驱动层只读单圈字段（`bus.rs` 的注释写着 "masks around rather than solves"），超出的
读数被取模屏蔽——于是"目标 == 实测"看着一切正常，其实差着一整圈，**下一次写目标就把
关节转回去一整圈**。2026-10-05 真机：`head_yaw` 读到 **6289**，`robotctl robot init`
时脖子飞快转了两圈，并且把相邻的 `head_roll` 顶进了过流错误（status `0x08`），
连 `robotctl robot relax` 都写不进去（"cannot cut torque"）。

初始化流程现在会**检查并修复**这一条：按**整圈挪 31 号位置偏移**把读数搬回窗口。
关节角是 `方向 · ((位置 mod 4096) − 2048)`，整圈平移对它不变，所以**物理姿态一动不动**；
只有整圈平移会超出偏移量程（±4095）时才失败，让人先把关节转回来。
**工具不在这里动相位**：全角度反馈是这批舵机的出厂约定，改它等于改整机的反馈表示；
真正需要改的是"读数跑出单圈之后没人管"这件事。

### 15 台列表的读法（点检 15 台 / 检测总线）

列表按 **ID 升序**排列（`10~14 / 20~24 / 30~34`），点一次 **点检 15 台** 或 **检测总线**
就逐个 PING 全部 15 个关节，把结果画成三种状态：

| 显示 | 含义 |
|---|---|
| 黄色（●） | 该 ID 在总线上**有应答**（来自 `census` / `precheck` 的 `present_joints`） |
| 绿色（✔） | **本页向导已经完成**过这个关节的初始化/校准（进度标记） |
| 灰色（序号） | 还没点检过，或无应答 |

列表与「下一个关节」的推进顺序都是 ID 升序；接口 `/api/joints` 本身仍按
`model.rs` 的 `JOINT_IDS` 顺序（左腿→头颈→右腿）返回，界面只改显示顺序。

点检结果表会同时列出每个在线舵机的**多圈状态**与 **19 号卸载条件**（含打开的保护位名），
方便装配前一眼看出哪台舵机的零位/保护配置与预期不同。点检是**完整点名**：
本次没有应答的关节会被清成灰色，不会留下上一次的黄点。

### 04 页「中位校准（CAL）」的保存选项

CAL 把**此刻的物理位置**写成单圈中点 **2048 计数（180°）**，并改写 **31 号位置偏移**
（EPROM 字段）。写入锁打开（55 号 = 1）时 EPROM 写入**掉电不保存**，所以厂商的
`CalibrationOfs()` 必须先解锁（55 号 = 0）再 CAL——这一步是必要的，不是可选项。

区别只在于 CAL 之后要不要补一次上锁，界面上就是那个默认勾选的
**「保存到 EPROM 并重新上锁」**：

| 勾选 | 实际动作 | 什么时候用 |
|---|---|---|
| **勾选（默认）** | 解锁 → CAL → **55 号写回 1** | 常规：校准结果已经写完并保存，上锁只是恢复到“EPROM 掉电不保存”的保护状态，不留一颗没上锁的舵机 |
| 取消勾选 | 解锁 → CAL（**保持解锁**） | 连续做多次 CAL / 偏移调试时，省掉每次重新解锁 |

两种情况下**校准结果本身都已经掉电保存**（因为 CAL 是在解锁状态下写的）；
上锁发生在写完之后，不会撤销这次校准。

### 位置环增益：为什么初始化要写它（真机实测）

`robotd` 启动时会按 `robotd.toml` 的 `gain` 把 **RAM 50（Kp）** 覆盖成它自己的值
（`duck-control/src/bus.rs` 的 `set_gain`），而那份配置的默认值 `gain = 200` 是给
Dynamixel XL330 的 **0..16383** 标度调的——在飞特的 **0..254** 上就是顶格。

| RAM 50（Kp） | left_hip_yaw（ID 20）实测 |
|---|---|
| 200 | 自激振荡：峰值电流 4966–5388 mA、目标不动时自报速度 4.37 rad/s、壳温升到 **74 °C** 且持续上升、人耳听到剧烈抖动 |
| **32**（厂商默认） | 峰值 110 mA、平均 20 mA、速度峰值 0.307 rad/s、通电 6 s 温度不变（48→49 °C） |

同一只鸭子、同一份固件、只改这一个数值；其余 14 台在两种增益下电流都接近 0。
所以初始化默认写 32/0，并且**两处都写**（EEPROM 让舵机自己上电时是对的，
RAM 让它不必等下一次上电）。注意这只是台面结论：真正的稳定裕度要按关节在负载下整定。

### 四种初始位置校准方式

| 方式 | 做什么 | 用在哪 |
|---|---|---|
| 中位校准（CAL） | 执行厂商 `CAL(0x0B)`，把**此刻的物理位置**写成 **2048 计数** = 关节角 0，并改写 31 号位置偏移 | 想让所有舵机有一个统一的机械基准时；语义确定、实测可复现。15 台现在就是这个状态 |
| 按 home 姿态写位置偏移 | 把 31 号位置偏移改成「此刻读数 = 该关节 home 姿态角」，目标计数 = **2048 + 方向 × home 角计数**（left_hip_pitch → **2347**） | 整机对齐 `DEFAULT_POSITION`；工具按**正反两种约定**各有界搜索候选偏移、逐个回读验证（见上文实测 3），全不中就把原偏移写回并报失败 |
| 转到中位（2048） | 写目标位置 **2048**（关节角 0、一圈中点），到位后保持扭矩，便于按舵盘标记装配（不写 EPROM） | 推荐：装舵盘时把机械零位定好，31 号偏移保持 0。注意不是写 0——0 是一圈的另一端（≈ −180°） |
| 不校准，只改 ID | 只写 ID/波特率，零位由机械装配决定 | 装好之后再整体校准 |

“重新初始化”模式（界面上可切换）把源 ID 从出厂 ID 1 改成目标 ID 本身，
用于重新编号或**重新校准一颗已经编过号的舵机**；这个模式下不会改写主 ID。

### 真机实测（三条结论，按重要性排列）

在 HD-1910-C001（固件 3.46）上实测。

**1. 出厂设置下负的目标位置不生效——但整机现在不需要负值。**

| 9 号 / 11 号角度限制 | 写目标 −500 | 42 号（目标）回读 | 56 号（当前） | 67 号（目标回读） |
|---|---|---|---|---|
| 0 / **4095**（出厂） | 被接受 | `−500` (0x81F4) | **`0`，舵机没动** | **`0`** |
| 0 / **0**（多圈） | 被接受 | `−500` (0x81F4) | **`−500`** | **`−500`** |

协议层一直「接受」负值（42 号回读就是 −500），但 11 号 = 4095 把位置坐标夹在一圈
`[0, 4095]` 内，负目标被夹到 0。厂商内存表在 9/11 号上写的「多圈绝对位置控制时此值为 0」
就是开关，实测有效。

> **2026-10-05：这条对整机的结论已经反过来，别照旧读。** 关节表里有 4 个 home 姿态角是负的，
> 但工具写下去的**从来不是负值**：单圈 + 「零点 2048、方向 −1」这套坐标把负角表示成 2048
> **以上**的计数（left_hip_pitch −299 → 2347），所以单圈就够了，**不需要**为这 4 个关节
> 打开多圈。现在整机按单圈跑（`robotd` 的审计也要求 9/11 = 0/4095），界面上的开关默认关闭
> 就是整机配置；打开它只在台面上要转到一圈以外、或要写有符号绝对值时才用。

**2. 推荐配置：多圈打开 + 位置偏移保持 0，零位由机械装配决定。**

打开多圈、31 号偏移为 0 时坐标是干净的，负目标精确跟随：

| 写目标 | 当前位置 | 67 号目标回读 |
|---|---|---|
| 0 | 0 | 0 |
| −500 | **−500** | **−500** |
| −1000 | **−999** | **−1000** |
| −300 | **−301** | **−300** |

也就是说：把舵盘装在 home 姿态、让 home 姿态的读数落在目标附近，然后把 31 号偏移
留给「小幅修正」——这条路径实测最稳。代价是固件不再限制行程，行程要靠 `robotd` 兜住。

**3. 拿大偏移去搬原点：那条"重锚"其实可以复算成取模回绕。**

写一个较大的偏移会让固件把编码器坐标**重锚**：实测偏移 −3591→−3091（+500）后读数从
−4096 变成 −500（差 3596），而 −3591→−4591（−1000）后读数从 −4096 变成 −3096（差 1000）
——同一根轴，写偏移前后的差值不是同一个常量；读数还总被折进约 ±2 圈的窗口。
手册没写这些（`docs/飞特通讯协议说明.md` 第 12.5 节把它列为未确认项）。

> **2026-10-05 复算：那四个点其实都满足 `位置 + 偏移 = −7687`（常数）**，也就是
> `位置 = 编码器 − 偏移` 的线性关系成立，"差值不是常量"是因为读数被折进窗口后再读出来的
> 是**回绕值**（−4596 读成 −500 之类）。所以严格说不是"重锚"，而是"显示窗口取模"。
> 这条目前只是**事后复算**，还没有按公式在真机上写过；等实测确认后再把下面的有界搜索
> 换成一次公式写入。在那之前维持原样。

所以「按 home 姿态写位置偏移」这个校准**不做公式假设**：有界搜索候选偏移（正反两种约定
都试）、逐个回读验证，只有落进 8 计数（≈0.70°）容差才算成功；全都不中就把原偏移**写回去**
并报失败。经验规律是**所需偏移越小越可靠**，所以校准前让读数落在 0 附近最省事
（舵盘换个齿位即可）。

另外两条实测结论：

- **CAL 的「中点」是 2048 计数（180°），不是 0**：CAL 前 偏移 = 0、位置 = 72；
  CAL 后 偏移 = −1976、位置 = 2048。
- 一圈内模式下位置被夹在一圈内，负结果回绕成 `4096 + 值`
  （偏移扫一圈时 −98 → 3999、−498 → 3599、−1998 → 2099）。
- **19 号「卸载条件」出厂只开过热保护**：2026-10-03 在 16 台 HD-1910-C001
  （固件 3.46）上逐台回读，`19 = 4 (0x04)`，即 BIT2 过热保护打开、BIT0 电压、
  BIT1 磁编码、BIT3 过流都**没有**打开。工具的「只按读改写动 BIT0/BIT3」就是按这个
  事实设计的：勾选/取消电压或过流时，BIT1/BIT2 保持原值（真机验证：`4 → 13 → 4`，
  BIT2 全程为 1）。

对 `microduck` 的影响：`duck-control/src/feetech.rs` 的 `position_rad()` 按「BIT15 为方向位」
解读位置字段，与 `DEFAULT_POSITION` 的负角一致；打开多圈后舵机给的正是这种写法。
仍然建议上整机前以 `robotd` 侧读到的关节角复测一次。

校准只改坐标原点，不校验机械姿态：勾选「已把该关节摆到基准位」只是确认你摆好了。
想恢复出厂零位，把 31 号位置偏移写回 0；想恢复一圈行程，把 11 号写回 4095。

### 界面之外：对应 API

| 用途 | 接口 |
|---|---|
| 关节表与校准方式 | `GET /api/joints` |
| 上电预检（该在的在、不该在的别在） | `POST /api/provision/precheck` |
| 初始化一颗（写 ID/波特率/多圈/**位置环增益**/校准/上锁/回读） | `POST /api/provision` |
| 点检 15 台谁在线 | `POST /api/provision/census` |

`POST /api/provision` 的参数：`id`（目标关节 ID）、`mode`（`fresh` / `reinit`）、
`calibrate`（`cal` / `offset` / `mid` / `none`）、`multiturn`（**默认 `false`**；
`true` 把 9/11 号写成 0/0，`false` 写回 0/4095 单圈行程）、
`protect_voltage` / `protect_over_current`（19 号 BIT0/BIT3，**默认都 `false`**）、
`write_response_level`、`write_gain`、`gain_kp` / `gain_kd`、`speed`、`acc`。
返回逐步的 `steps` 明细、`calibration` 实测值、`multiturn` / `protect` 回显和
`snapshot` 回读结果（`snapshot` 里含 `unload_condition` 与 `protect_voltage` /
`protect_over_current`）。

`POST /api/calibrate` 的参数：`id`，以及 `save`（**默认 `true`**）——
`true` 时解锁 → CAL → 补写 55 号 = 1，`false` 时保持解锁；返回里的 `saved`
与 `lock`（上锁应答帧或 `null`）说明实际做了什么。

### 安全须知

- **一次只接一个新舵机**：两颗出厂 ID 都是 1 的舵机同时在线时会被一起改名，
  产生重复 ID，之后整条总线的读写都会互相打架。
- 初始化会写 EPROM，并且 CAL / 转到位置 0 会让舵机转动，请先确认机械安全、可以随时断电。
- 用 CAL 或位置偏移校准前，先确认这颗舵机确实处在它该在的基准位。
- **电压 / 过流保护（19 号）默认不打开**：它们触发时舵机会卸载（不再输出扭矩），
  对一条腿站着的机器人等于摔倒。要在整机上打开就明确知道自己在换什么。
- 想恢复出厂零位，把 31 号位置偏移写回 0 并重新上电即可。

## 内存表关键换算

| 字段 | 换算 |
|---|---|
| 位置 42/56/67 | 1 计数 = 0.087°，4096 计数/圈；手册称 BIT15 方向，实测本机负值写法不稳定（见上文实测） |
| 速度 46/58 | 1 计数 = 0.732 RPM，BIT15 方向 |
| 负载 60 | 1 计数 = 0.1% 占空比，BIT10 方向 |
| 电压 62 | 1 计数 = 0.1 V |
| 电流 44/69 | 1 计数 = 6.5 mA，BIT15 方向 |
| 加速度 41 | 1 计数 = 8.7 °/s²，0 = 最大 |
| 转矩 16/48 | 1 计数 = 0.1% |
| Kp/Kd 50/51 | 位置模式 Kp 刻度 1/8，Kd 刻度 1/4 |
| 位置偏移 31 | 1 计数 = 0.087°；实测 `位置 ≡ 编码器 − 偏移 (mod 4096)` |

特别提醒：HLS 位置是 **4096 计数/圈**，不是 32768 计数/圈。
早期资料若按 32768 计算会有 8 倍误差。

## 与参考库的对应关系

| 参考库方法 | 工具入口 | HTTP API |
|---|---|---|
| `Ping(ID)` | Ping / 扫描 | `POST /api/ping` |
| `Read/readByte/readWord` | 通用读、参数配置、实时反馈 | `POST /api/read` |
| `genWrite/writeByte/writeWord` | 通用写、参数配置 | `POST /api/write`、`POST /api/write_field` |
| `regWrite` | 异步写 | `POST /api/reg_write` |
| `RegWriteAction` | 执行异步写 | `POST /api/reg_action` |
| `WritePosEx` | 位置控制 | `POST /api/move` |
| `RegWritePosEx` | 异步写位置 | `POST /api/move` (`reg=true`) |
| `SyncWritePosEx` | 同步位置写 | `POST /api/sync_move` |
| `SyncWriteSpe` | 同步速度写 | `POST /api/sync_wheel` |
| `ServoMode/WheelMode/EleMode` | 模式按钮 | `POST /api/mode` |
| `WriteSpe` | 恒速模式 | `POST /api/wheel` |
| `WriteEle` | 恒流模式 | `POST /api/electric` |
| `EnableTorque` | 扭矩开关 | `POST /api/torque` |
| `unLockEprom/LockEprom` | 写锁控制 | `POST /api/lock` |
| `CalibrationOfs` | 中位校准 | `POST /api/calibrate` |
| `FeedBack` | 实时反馈 | `POST /api/feedback` |
| `Reset` | RESET | `POST /api/reset` |
| `Recal` | CAL | `POST /api/calibrate` |
| 原始协议 | 原始帧收发 | `POST /api/raw` |
| 整机初始化 | 舵机初始化页签 | `GET /api/joints`、`POST /api/provision/precheck`、`POST /api/provision`、`POST /api/provision/census` |

## 故障排查

- **爆出“打开串口失败”**：检查设备名、USB 线、供电、`dialout` 权限。
- **一直等待应答超时**：优先检查波特率是否匹配；HLS 默认 1 Mbps。
- **Ping 收到但读写失败**：确认 ID 是否为总线地址/副 ID；确认目标设备不是只响应主 ID。
- **写 EPROM 不保存**：写 55 号锁标志为 0（关闭写入锁）后再写，然后重新上电验证。
- **修改 ID/波特率后连不上**：换用新 ID/新波特率重新连接。
- **同步写没反应**：SYNC_WRITE 是广播，没有应答；先确认舵机处于正确模式，且每个 ID 的数据长度一致。
- **位置角度不对**：按 4096 计数/圈换算，且**零点在 2048、方向是 −1**
  （`关节角 = −(计数 − 2048) · 0.0879°`）。扭矩关掉后位置可能可以手动转动，这是正常现象。
- **负角关节不进反方向 / 写负位置舵机不动**：出厂 11 号最大角度限制 = 4095 把行程
  锁在一圈内，**负数**目标会被夹到 0。整机现在不需要负值——单圈 + 「零点 2048、方向 −1」
  把负的关节角表示成 2048 以上的计数（left_hip_pitch −299 → 2347），所以保持单圈即可。
  只有台面上要转到一圈以外时才用「舵机初始化」页签勾上「打开多圈绝对位置控制」，
  或手动把 9 号与 11 号都写 0。实测对照见上文《真机实测》。
- **位置偏移校准报「没能把读数调到…已把位置偏移恢复为…」**：说明当前读数离目标
  太远。把关节摆到更接近 home 的位置，或把舵盘换个齿位让读数落在目标附近再校准；
  工具已经把偏移恢复成原值，不会留半校准状态。
- **初始化说“ID 1 没有应答”**：确认只接了新舵机、已上电、波特率是 1 Mbps；
  用“连接与扫描”里的“自动探测 ID1”或全总线扫描确认它到底在不在。
- **初始化说“目标 ID 已经在应答”**：这个关节已经编过号了。要么换一颗新舵机，
  要么把界面上的模式切到“重新初始化”。
- **初始化说“目标 ID 是 20 却报 ID 是别的”**：多半是总线上有重复 ID，
  或者目标 ID 的舵机不是你以为的那一颗。先用“点检 15 台”看清楚谁在线。
- **CAL 之后读数是 2048**：这是正确的——**2048 就是关节角 0**，与 robotd 的驱动层一致，
  不是旧文档里说的“180° 中点所以不对”。想看 home 姿态该读多少，用上表的「舵机字段」列
  （left_hip_pitch 是 **2347**）。
- **负角关节的偏移校准目标是多少**：`2048 + 方向 × home 角计数`。`left_hip_pitch` 的 home 角
  是 −299 计数、方向 −1，所以目标是 **2347**（不是 −299，也不是 1749——1749 是**镜像**位置）。
  界面上会直接把目标数打出来。
- **我照着一张写着 1749 的表把关节摆过去了**：那张表是 2026-10-03 方向翻转之前的，
  整列镜像。正确值见上表；摆错的后果是 15 个关节全部对到镜像位置（`robotctl monitor`
  会显示每个关节读 π 附近或明显反向）。
- **明明取消了多圈、9/11 号却还是 0/0**：这是旧版的行为（取消勾选只是“跳过不写”）。
  现在两个方向都会真的写寄存器，取消勾选就把 9/11 号写成 0/4095；如果回读仍不是，
  看结果框里的「关闭多圈，恢复单圈行程」那一步回读值是多少。
- **点检后黄点/绿点不对**：黄点来自最近一次「点检 15 台」或「检测总线」的完整点名，
  绿点是**本页**的完成标记（刷新页面会清掉），两者都不代表舵机的零点真的校好了。
- **扫描少发现舵机（已修）**：早期扫描范围默认只到 ID 20，把 ID>20 的舵机整段漏掉
  （实测 10~14、20、21 共七台只报 6 台，漏的正是 21）。现已把界面、`/api/scan`、
  `HLSBus.scan()` 的默认上限全部改为 **253**，默认全总线扫描约 12 秒。
  注意扫描区间是**闭区间**：结束 ID 必须 ≥ 最大舵机 ID。
- **写运行模式 4 被拒绝（已修）**：`HLSBus.set_mode()` 原先按手册的 `0~3` 校验，
  但本机型出厂就是模式 4（与模式 0 同属位置环），界面上的“位置 (4)”按钮因此会报错。
  现已放开到 `0~4`。

## 安全提示

调试软件可以通过浏览器直接驱动舵机。所有写入都会立即发送到总线，
请务必：
- 固定好机械结构，避免堵转、飞车或夹伤；
- 初次使用低速度、低加速度、低电流；
- 随时准备断开舵机电源；
- **注意：写目标位置会自动打开扭矩**（实测本固件行为），所以"关闭扭矩"后
  再写位置会重新带电；需要卸力时请在最后一次位置写入之后再点"关闭扭矩"。
  这一条对机器人软件同样成立，而且是 `robotctl robot relax` 曾经"卸不了力"的原因：
  控制环每个 tick 都会写目标位置，于是卸力只维持了不到 20 ms。修法见
  `microduck_feetech/FORK.md` 的「`robot relax` 卸不了力」一节与
  `duck-control/src/safety.rs` 的 `Safety::powered`；
- 不要把 `RESET`、`CAL`、改 ID/波特率等操作当成常规测试按钮反复点击；
- 整机初始化会写 EPROM，而且 CAL / 转到位置 0 会让舵机动起来；
  **一次只接一个新舵机**，否则两颗出厂 ID 1 的舵机会被一起改名，产生重复 ID；
- 重复 ID 会让总线上所有读写互相打架，且症状像接线故障，接线时务必一颗一颗来。

## 无硬件自检

不连接舵机也可以运行协议自检，验证帧构造、校验和、串口读取状态机、
同步读解析、内存表编解码、反馈解码，以及用一个从站模拟跑完整套
“出厂 ID 1 → 关节 ID + 校准”的初始化流程：

```bash
uv python -m hls_debugger.selftest
```

## 真机连通性测试

`hw_test.py` 用真实串口完成只读验证（只发 PING 和 READ，不发任何运动指令）：

```bash
uv python hw_test.py --port /dev/ttyACM1
```

它会打印设备信息、各波特率下的 ID 扫描、版本/ID/波特率/模式/扭矩/写锁，
以及 56~70 号 15 字节实时反馈的完整解码。若首个波特率无应答，会自动遍历
`1000000 / 115200 / 500000 / 250000 / 128000 / 76800 / 57600 / 38400`。

### 现场注意

- 波特率索引 0 = 1 Mbps，与本工具默认一致；改波特率后需按新速率重连。
- 锁标志为 1 时写 EPROM 掉电不保存，**改 ID/波特率等需先解写锁（55 号写 0）**。
- 位置偏移会把读数整体平移，且按一圈取模；负值有时报负、有时回绕，属实测现象。
  校准请用“舵机初始化”页签，它按一圈取模比较、留容差并回读校验。

## 实机操作记录（供复现参考）

以下步骤在本工具上对真机跑通过，可作为复现脚本的参照：

1. 接上出厂新舵机到 `/dev/ttyACM0`，连接后 `POST /api/provision/precheck {"id":20,"mode":"fresh"}`：
   `source_present=true`、`target_present=false`。
2. `POST /api/provision {"id":20,"mode":"fresh","calibrate":"cal"}`：
   ID 1 → 20，波特率 0，应答级别 1，CAL 把位置 72 写到 2048，上锁，状态 0。
3. `POST /api/provision {"id":20,"mode":"reinit","calibrate":"mid","speed":80,"acc":20}`：
   输出轴从 2048 转到 0（误差 2 计数 ≈ 0.18°），扭矩保持开启。
4. `POST /api/provision {"id":20,"mode":"reinit","calibrate":"offset"}`：
   位置偏移 3000 → 2121，读数 3217 → 0，校验通过。
5. `POST /api/provision/census`：应报出全部已编号的关节，未编号的位置显示“—”。

### 2026-10-03：本轮改动的真机验证（`/dev/ttyACM0`，16 台在线）

总线上是 16 台 HD-1910-C001（固件 3.46 / 舵机 10.31）：ID `1, 10~14, 20~24, 30~34`，
1 Mbps。测试**全部可逆**，结束前逐项写回，收尾用同一份只读盘点与测试前逐字节比对。

| 验证项 | 结果 |
|---|---|
| 9/11 号两个方向（`_set_multiturn`） | `0/4095 → 0/0 → 0/4095` 全部回读一致（ID 1） |
| 19 号读改写 | `4 (0x04) → 13 (0x0D) → 4 (0x04)`，BIT2 过热全程保持为 1（ID 1） |
| 55 号解锁/上锁 | 解锁回读 0、上锁回读 1（ID 1） |
| CAL 保存（`save=True`） | 解锁 → CAL（位置 1 → 2048、偏移 0 → −2047）→ 补写 55 = 1；随后把偏移写回 0，读数恢复 1 |
| 整流程 `provision(mode=reinit)` | 对在线关节 ID 20 跑完 14 个步骤全部 OK，含“关闭多圈，恢复单圈行程”与
“写卸载条件（19 号）”两步和最终回读校验（单圈行程 + 卸载条件都在校验项里） |
| 收尾比对 | 16 台的 9/11、19、31、相位、模式、扭矩、锁、增益、ID 与测试前完全一致 |

过程中的两点观察：本轮之前 15 台关节的 9/11 **都是 `0/0`（多圈）**、31 号偏移都是 0，
19 号都是 `4`；而 ID 10 是唯一被手工改过的（`9/11 = 0/4095`、`19 = 13`、偏移 −595、
锁 0），说明这些寄存器确实被独立写过、回读可信。另外 `snapshot()` 现在多读一个 19 号，
点检 15 台会因此多 15 次单字节读——实测 15 台总耗时仍在 1~3 秒量级。

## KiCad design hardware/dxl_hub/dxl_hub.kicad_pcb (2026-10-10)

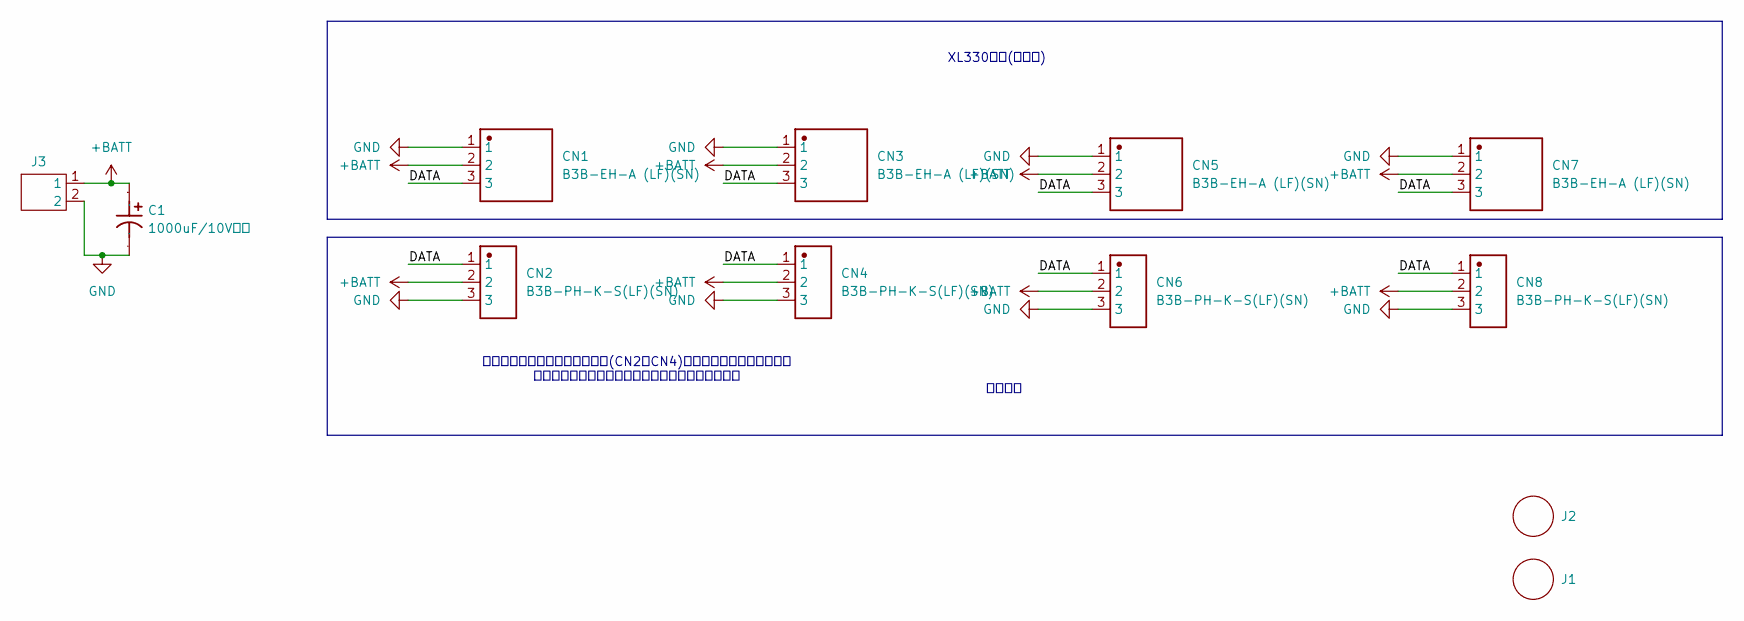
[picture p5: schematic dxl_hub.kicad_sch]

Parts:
C1: 1000uF/10V固态; CAP-TH_BD8.0-P3.50-D0.5-FD; Manufacturer Part SPZ1AM102F11000RAXXX
CN1, CN3, CN5, CN7: B3B-EH-A (LF)(SN); CONN-TH_B3B-EH-A-LF-SN
CN2, CN4, CN6, CN8: B3B-PH-K-S(LF)(SN); CONN-TH_B3B-PH-K-S
J1, J2: 1.8mm螺丝孔; pad
J3: pad-2(thru)

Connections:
+BATT: C1.1, CN1.2, CN2.2, CN3.2, CN4.2, CN5.2, CN6.2, CN7.2, CN8.2, J3.1
/DATA: CN1.3, CN2.1, CN3.3, CN4.1, CN5.3, CN6.1, CN7.3, CN8.1
GND: C1.2, CN1.1, CN2.3, CN3.1, CN4.3, CN5.1, CN6.3, CN7.1, CN8.3, J3.2

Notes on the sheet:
飞特接口
上一版本发现正面焊接卧式插座(CN2、CN4)，与鸭脖子舵机有少许干涉 改为背面立式插座，正面舵机线束需要绕到背面插上
XL330接口(二选一)

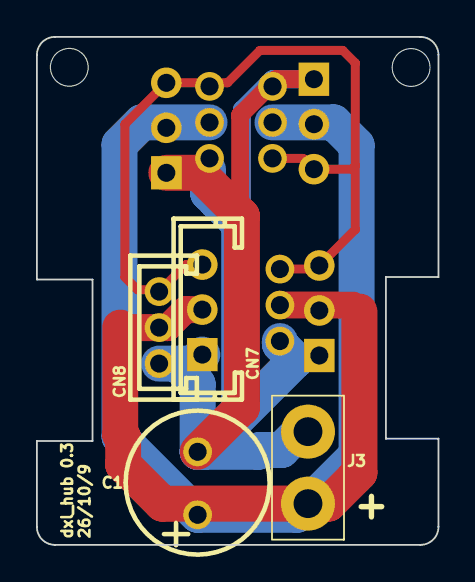
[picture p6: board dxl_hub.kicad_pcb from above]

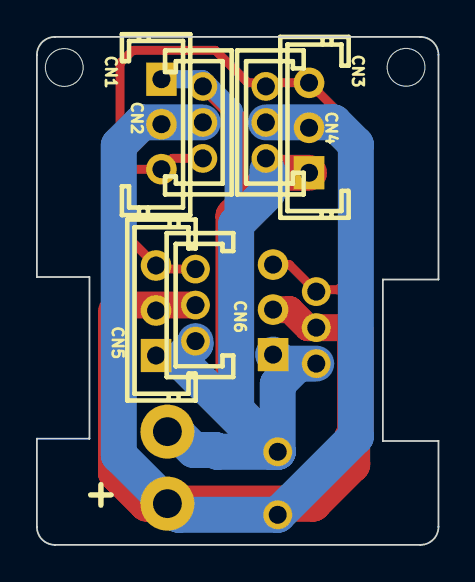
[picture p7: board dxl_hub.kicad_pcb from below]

Board: 2 copper layers, 22.3 x 28.2 mm, 12 parts (6 on the bottom side), 3 nets.

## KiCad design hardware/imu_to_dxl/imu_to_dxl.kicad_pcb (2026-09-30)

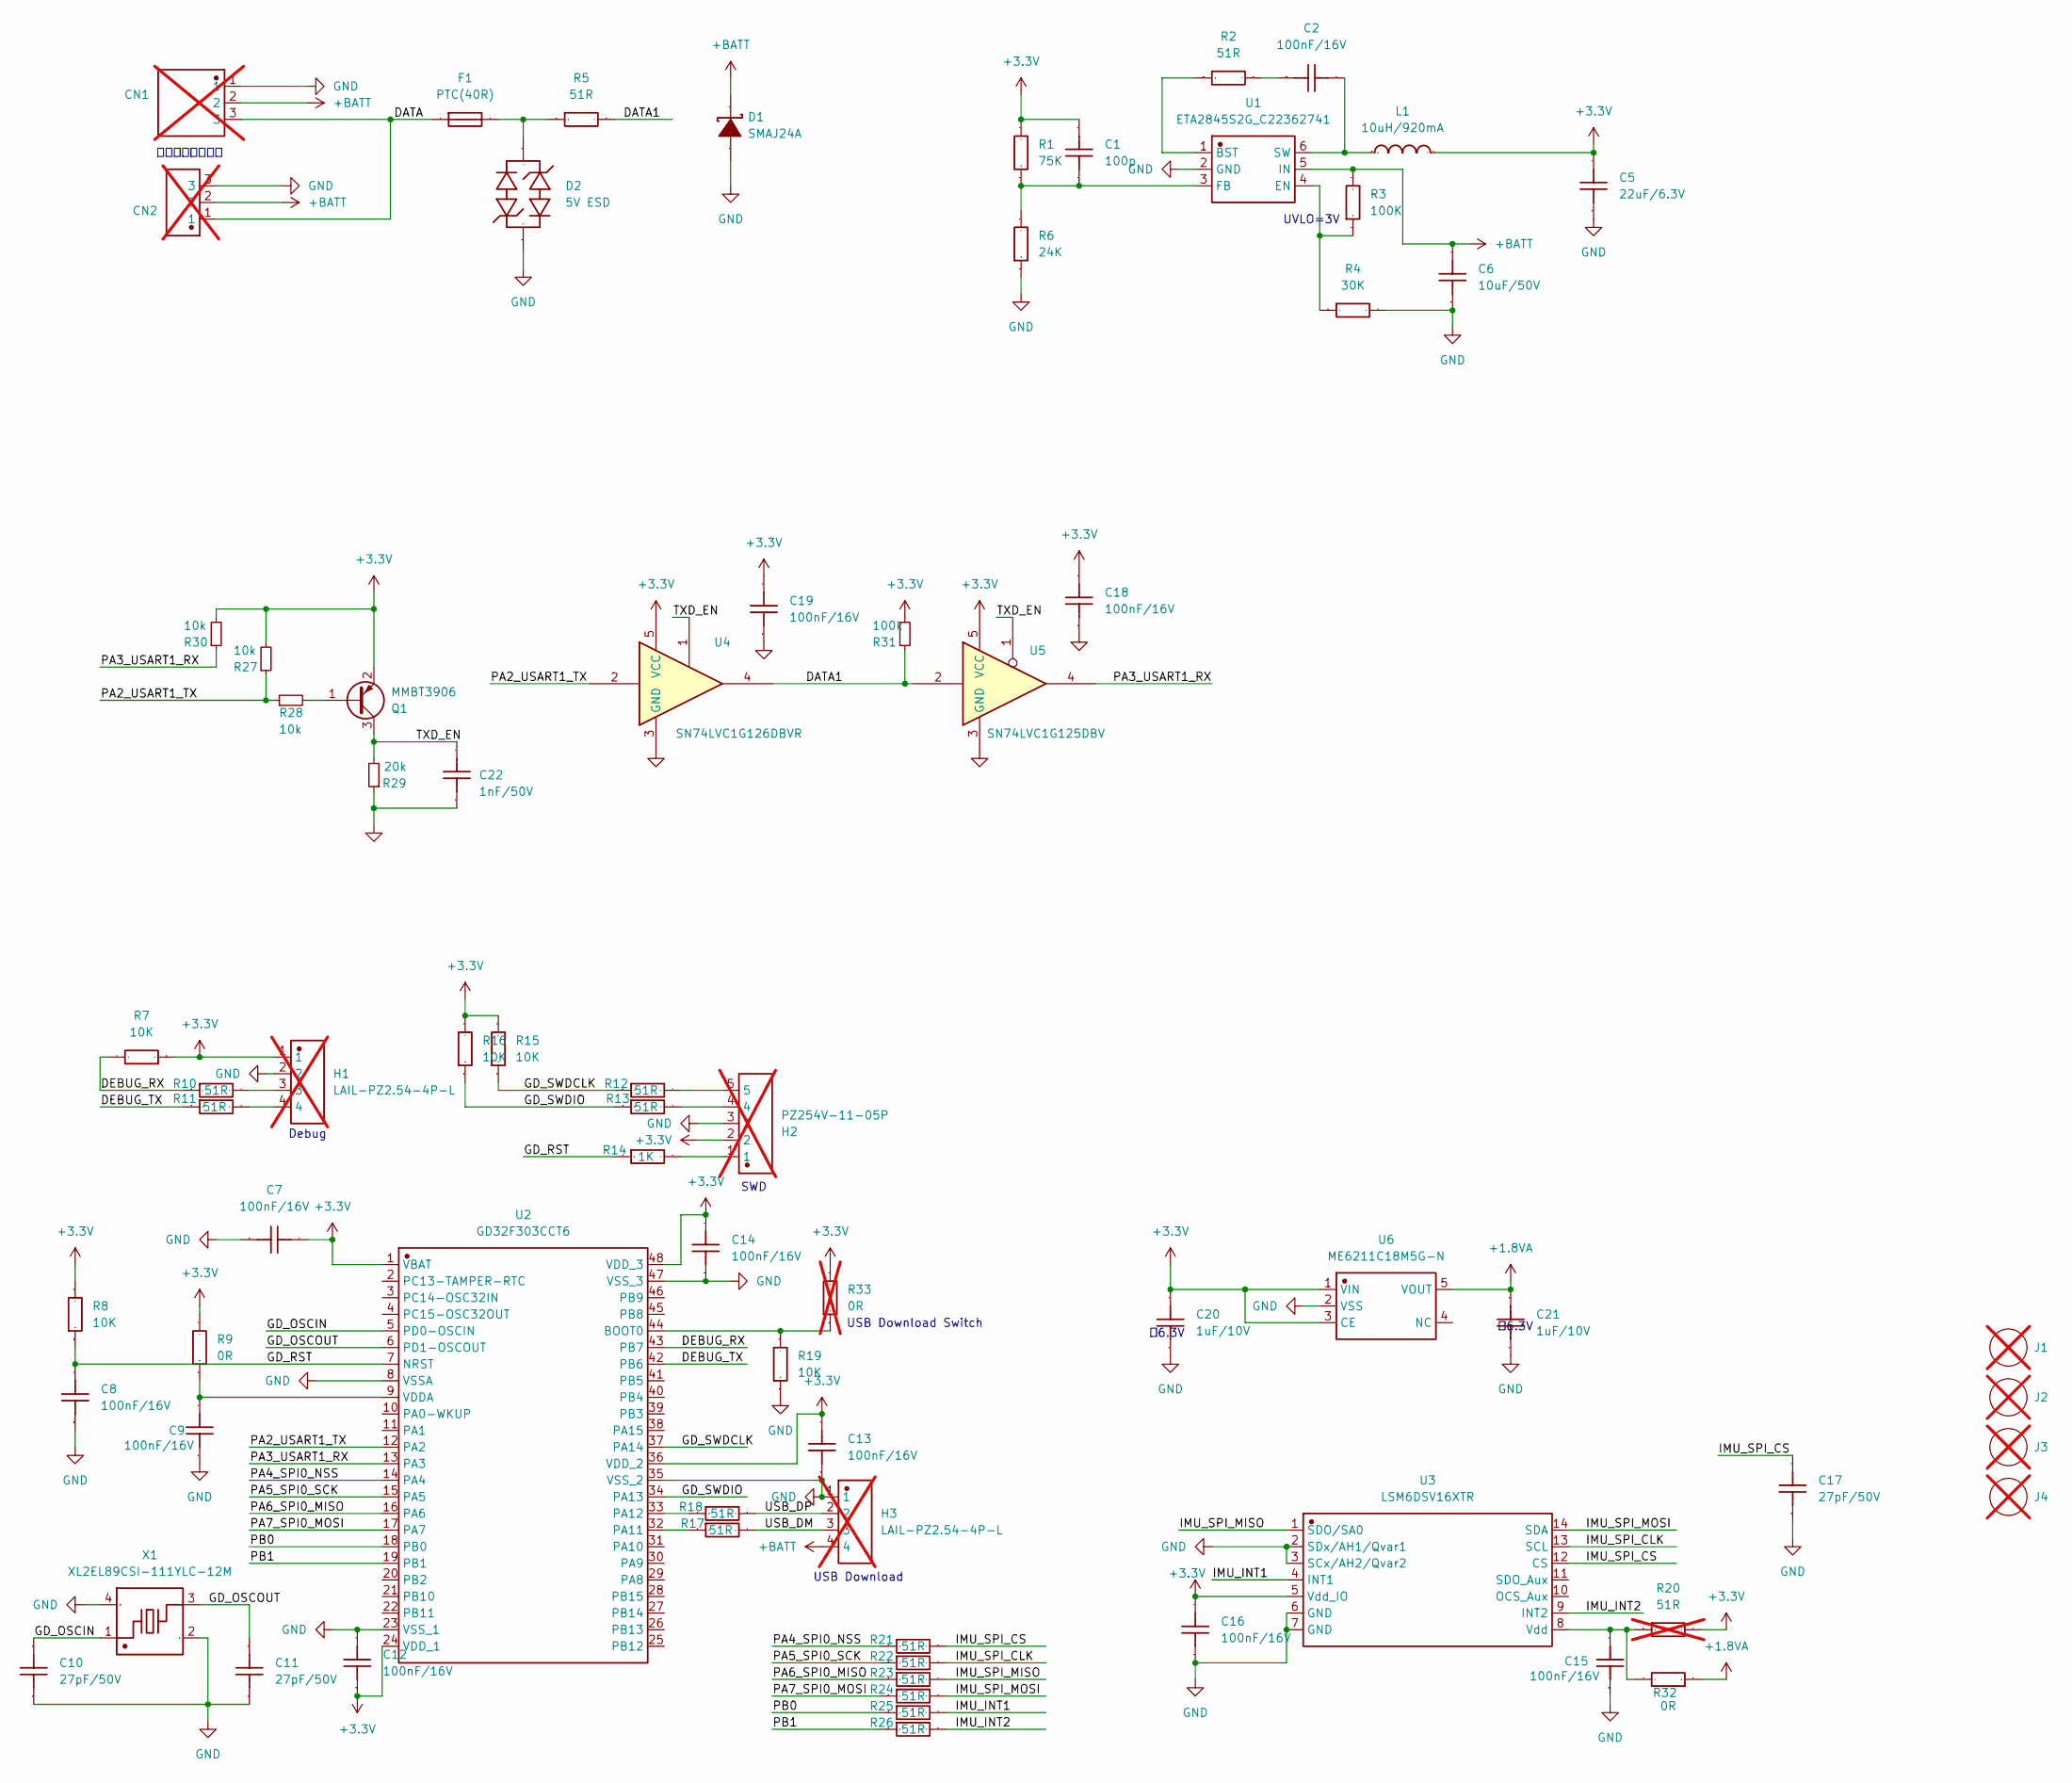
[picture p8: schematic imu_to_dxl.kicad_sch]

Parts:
C1: 100p; C0402; LCSC Part C106200
C2, C7, C8, C9, C12, C13, C14, C15, C16, C18, C19: 100nF/16V; C0402; LCSC Part C1525
C5: 22uF/6.3V; C0603; LCSC Part C59461
C6: 10uF/50V; C0805; Manufacturer Part CL21A106KBYQNNE; LCSC Part C2932476
C10, C11, C17: 27pF/50V; C0402; LCSC Part C107002
C20, C21: 1uF/10V; C0402; LCSC Part C106254
C22: 1nF/50V; C0402; LCSC Part C106205
CN1: CONN-TH_B3B-EH-A-LF-SN; not fitted
CN2: CONN-TH_B3B-PH-K-S; not fitted
D1: SMAJ24A; SMA_L4.4-W2.6-LS5.0-RD; Manufacturer Part SMAJ24A/TR13; LCSC Part C90510
D2: 5V ESD; SOD-323_L1.7-W1.3-LS2.5-BI; LCSC Part C19224
F1: PTC(40R); F0603; Manufacturer Part JK-SMD0603-001; LCSC Part C2687114
H1, H3: LAIL-PZ2.54-4P-L; pad-4; Manufacturer Part LAIL-PZ2.54-4P-L; LCSC Part C54950602; not fitted
H2: PZ254V-11-05P; pad-5; Manufacturer Part PZ254V-11-05P; LCSC Part C492404; not fitted
J1, J2, J3, J4: 1.8mm螺丝孔; pad; not fitted
L1: 10uH/920mA; IND-SMD_L3.0-W3.0_SWPA3010S; Manufacturer Part SWPA3015S100MT; LCSC Part C45403
Q1: MMBT3906; SOT-23; LCSC Part C727128
R1: 75K; R0402; LCSC Part C144737
R2, R10, R11, R12, R13, R17, R18, R21, R22, R23, R24, R25, R26: 51R; R0402; LCSC Part C137960
R3: 100K; R0402; LCSC Part C25741
R4: 30K; R0402; LCSC Part C25776
R5: 51R; R0603; LCSC Part C2907181
R6: 24K; R0402; LCSC Part C138026
R7, R8, R15, R16, R19: 10K; R0402; LCSC Part C25744
R9, R32: 0R; R0402; LCSC Part C60485
R14: 1K; R0402; LCSC Part C11702
R20: 51R; R0402; LCSC Part C137960; not fitted
R27, R28, R30: 10k; R0402; LCSC Part C25744
R29: 20k; R0402; LCSC Part C25765
R31: 100k; R0402; LCSC Part C25741
R33: 0R; R0402_Jumper; LCSC Part C60485; not fitted
U1: ETA2845S2G_C22362741; SOT-23-6_L2.9-W1.6-P0.95-LS2.8-BR; Manufacturer Part ETA2845S2G; LCSC Part C22362741
U2: GD32F303CCT6; LQFP-48_L7.0-W7.0-P0.50-LS9.0-BL; Manufacturer Part GD32F303CCT6; LCSC Part C116151
U3: LSM6DSV16XTR; LGA-14_L3.0-W2.5-P0.50-BR; Manufacturer Part LSM6DSV16XTR; LCSC Part C5267406
U4: SN74LVC1G126DBVR; SOT-23-5; LCSC Part C46472327
U5: SN74LVC1G125DBV; SOT-23-5; LCSC Part C3040625
U6: ME6211C18M5G-N; SOT-23-5_L3.0-W1.7-P0.95-LS2.8-BR; Manufacturer Part ME6211C18M5G-N; LCSC Part C236671
X1: XL2EL89CSI-111YLC-12M; CRYSTAL-SMD_4P-L3.2-W2.5-BL; Manufacturer Part XL2EL89CSI-111YLC-12M; LCSC Part C5280576

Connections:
+1.8VA: C21.2, R32.1, U6.5 (VOUT)
+3.3V: C1.2, C5.2, C7.2, C12.1, C13.2, C14.2, C16.2, C18.2, C19.2, C20.2, H1.1, H2.2, L1.2, Q1.2 (E), R1.2, R7.1, R8.2, R9.2, R15.2, R16.2, R20.2, R27.2, R30.2, R31.2, R33.2, U2.1 (VBAT), U2.24 (VDD_1), U2.36 (VDD_2), U2.48 (VDD_3), U3.5 (Vdd_IO), U4.5 (VCC), U5.5 (VCC), U6.1 (VIN), U6.3 (CE)
+BATT: C6.2, CN1.2, CN2.2, D1.1 (K), H3.4, R3.2, U1.5 (IN)
/DATA: CN1.3, CN2.1, F1.1
/DATA1: R5.2, R31.1, U4.4, U5.2
/DEBUG_RX: R7.2, R10.1, U2.43 (PB7)
/DEBUG_TX: R11.1, U2.42 (PB6)
/GD_OSCIN: C10.2, U2.5 (PD0-OSCIN), X1.1
/GD_OSCOUT: C11.2, U2.6 (PD1-OSCOUT), X1.3
/GD_RST: C8.2, R8.1, R14.1, U2.7 (NRST)
/GD_SWDCLK: R12.1, R15.1, U2.37 (PA14)
/GD_SWDIO: R13.1, R16.1, U2.34 (PA13)
/IMU_INT1: R25.2, U3.4 (INT1)
/IMU_INT2: R26.2, U3.9 (INT2)
/IMU_SPI_CLK: R22.2, U3.13 (SCL)
/IMU_SPI_CS: C17.2, R21.2, U3.12 (CS)
/IMU_SPI_MISO: R23.2, U3.1 (SDO/SA0)
/IMU_SPI_MOSI: R24.2, U3.14 (SDA)
/PA2_USART1_TX: R27.1, R28.1, U2.12 (PA2), U4.2
/PA3_USART1_RX: R30.1, U2.13 (PA3), U5.4
/PA4_SPI0_NSS: R21.1, U2.14 (PA4)
/PA5_SPI0_SCK: R22.1, U2.15 (PA5)
/PA6_SPI0_MISO: R23.1, U2.16 (PA6)
/PA7_SPI0_MOSI: R24.1, U2.17 (PA7)
/PB0: R25.1, U2.18 (PB0)
/PB1: R26.1, U2.19 (PB1)
/TXD_EN: C22.2, Q1.3 (C), R29.2, U4.1, U5.1
/USB_DM: H3.3, R17.2
/USB_DP: H3.2, R18.2
GND: C5.1, C6.1, C7.1, C8.1, C9.1, C10.1, C11.1, C12.2, C13.1, C14.1, C15.1, C16.1, C17.1, C18.1, C19.1, C20.1, C21.1, C22.1, CN1.1, CN2.3, D1.2 (A), D2.1, H1.2, H2.3, H3.1, R4.2, R6.1, R19.1, R29.1, U1.2 (GND), U2.8 (VSSA), U2.23 (VSS_1), U2.35 (VSS_2), U2.47 (VSS_3), U3.2 (SDx/AH1/Qvar1), U3.3 (SCx/AH2/Qvar2), U3.6 (GND), U3.7 (GND), U4.3 (GND), U5.3 (GND), U6.2 (VSS), X1.2 (GND), X1.4 (GND)
unnamed: C2.1, R2.2
unnamed: D2.2, F1.2, R5.1
unnamed: H1.3, R10.2
unnamed: H1.4, R11.2
unnamed: H2.1, R14.2
unnamed: H2.4, R13.2
unnamed: H2.5, R12.2
unnamed: Q1.1 (B), R28.2
unnamed: R2.1, U1.1 (BST)
unnamed: R3.1, R4.1, U1.4 (EN)
unnamed: C1.1, R1.1, R6.2, U1.3 (FB)
unnamed: C2.2, L1.1, U1.6 (SW)
unnamed: R19.2, R33.1, U2.44 (BOOT0)
unnamed: R17.1, U2.32 (PA11)
unnamed: R18.1, U2.33 (PA12)
unnamed: C9.2, R9.1, U2.9 (VDDA)
unnamed: C15.2, R20.1, R32.2, U3.8 (Vdd)

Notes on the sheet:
UVLO=3V
Debug
二选一，手工焊接
SWD
USB Download
改6.3V
USB Download Switch

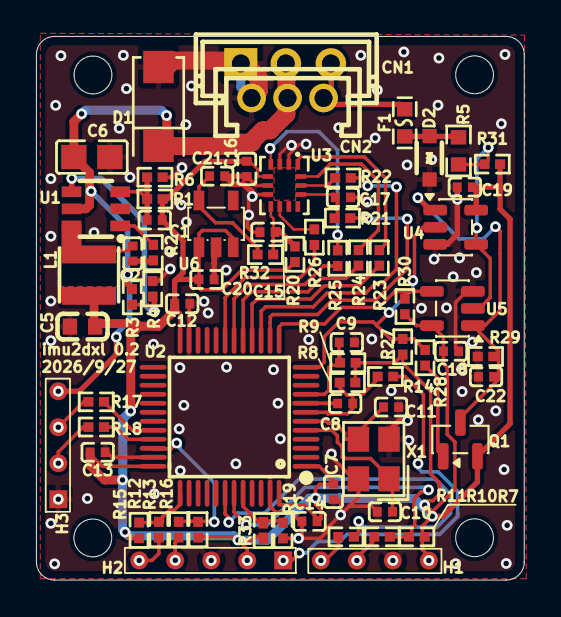
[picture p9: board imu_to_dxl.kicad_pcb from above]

Board: 2 copper layers, 27.1 x 30.2 mm, 74 parts (0 on the bottom side), 47 nets.

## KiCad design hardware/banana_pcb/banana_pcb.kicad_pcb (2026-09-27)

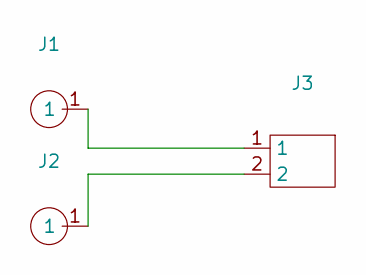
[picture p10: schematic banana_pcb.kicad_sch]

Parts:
J1, J2: banana_pin
J3: pad-2(surf)

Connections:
unnamed: J1.1, J3.1
unnamed: J2.1, J3.2

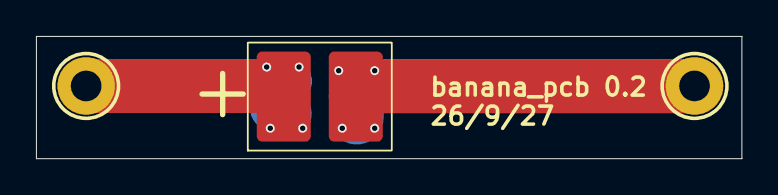
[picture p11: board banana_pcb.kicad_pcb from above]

Board: 2 copper layers, 39.2 x 6.8 mm, 3 parts (0 on the bottom side), 2 nets.

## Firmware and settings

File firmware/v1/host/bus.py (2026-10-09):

#!/usr/bin/env python3
"""Protocol codecs and serial link for the imu_to_dxl v1 node.

This module is the single source of truth on the host side for:

  * the Dynamixel protocol 2.0 framing (instruction/status, ROBOTIS CRC-16),
  * the FeeTech SCS/HLS framing (8-bit complement checksum),
  * the 20-byte IMU block layout and the mounting rotation microduck applies,
  * a serial `Link` that polls the node and decodes samples.

Everything here mirrors `src/*.c`; the constants and the
packet vectors are asserted against the C implementation by
`tools/bus_smoke.py --self-test` and `tools/test_protocols.c`.

Run `python3 bus.py` for the codec self test (no hardware needed).
"""

from __future__ import annotations

import math
import struct
import time
from dataclasses import dataclass, field
from typing import Iterable, Optional, Sequence

try:  # pyserial is only needed for the live link, not for the codecs
    import serial  # type: ignore
except Exception:  # pragma: no cover - import guard for self tests
    serial = None  # type: ignore

# ── constants, mirrored from src/board.h ────────────────────────────────────

DXL_BROADCAST = 0xFE
FEE_BROADCAST = 0xFE

PROTO_DXL = "dxl"
PROTO_FEE = "fee"

DXL_TELEM_ADDR = 124
FEE_TELEM_ADDR = 56
FEE_TELEM_ALT_ADDR = 128
DXL_VENDOR_ADDR = 148
FEE_VENDOR_ADDR = 160
DXL_READ_ADDR = DXL_TELEM_ADDR
FEE_READ_ADDR = FEE_TELEM_ADDR
#: Where the *20-byte* diagnostic block lives (accelerometer included).  The
#: FeeTech map answers at 56 with the 15-byte shape a real servo uses there, so
#: the diagnostic tail sits in the 128 alias instead; Dynamixel has room at 124.
DXL_DIAG_ADDR = DXL_TELEM_ADDR
FEE_DIAG_ADDR = FEE_TELEM_ALT_ADDR

# ── FeeTech personality (docs/imu_to_dxl_protocol.md §16) ───────────────────
#: The FeeTech map has two build-time personalities.  `native` is this
#: repository's own contract (the constants above); `ft6` is byte-compatible
#: with the FT6 node, which moves its diagnostic block to 124 and the native
#: 20-byte alias to 196.  A native reader cannot decode an ft6 node's status
#: byte, and vice versa, so the choice is explicit rather than guessed.
FEE_PERSONALITY_NATIVE = "native"
FEE_PERSONALITY_FT6 = "ft6"
FEE_PERSONALITIES = (FEE_PERSONALITY_NATIVE, FEE_PERSONALITY_FT6)
#: Identity registers 0..4 of an FT6 node.  Native answers 01 00 00 49 4D.
FEE_IDENTITY_FT6 = bytes([0x06, 0x00, 0x00, 0x00, 0xF2])
#: FT6 contract/diagnostic addresses.
FEE_DIAG_ADDR_FT6 = 124
FEE_TELEM_ALT_ADDR_FT6 = 196
#: FT6 status byte (address 69 / block offset 13).  Deliberately a *second*
#: table: TELEM_FLAG_BITS describes the native flags byte, and bit 0 means the
#: opposite thing in the two contracts.
FEE_ST_BITS = {
    "not_ready": 0x01,
    "stale": 0x02,
    "sensor_err": 0x04,
    "reader_slow": 0x08,
}
#: FT6 status bit1 is asserted once the quaternion age passes this bound.
FEE_ST_FRESH_MS = 30


def fee_diag_addr(personality: str = FEE_PERSONALITY_NATIVE) -> int:
    """Address of the FeeTech 20-byte diagnostic block for a personality."""
    return FEE_DIAG_ADDR_FT6 if personality == FEE_PERSONALITY_FT6 else FEE_DIAG_ADDR


def fee_alt_addr(personality: str = FEE_PERSONALITY_NATIVE) -> int:
    """Address of the *native* 20-byte block inside the FeeTech map."""
    return FEE_TELEM_ALT_ADDR_FT6 if personality == FEE_PERSONALITY_FT6 else FEE_TELEM_ALT_ADDR


def fee_ft6_status_names(status: int) -> list[str]:
    """Decode an FT6 status byte into names.  No bit above 3 is ever set."""
    return [name for name, bit in FEE_ST_BITS.items() if status & bit]


TELEM_LEN = 20
CTRL_LEN = 12
#: Longest Dynamixel frame the scanner will believe: one status packet is at most
#: 7 + 256 + 4 bytes, and a Fast Sync Read *aggregate* is longer still - it is
#: `8 + N*(X+4)` for every device in the id list (microduck's 16 devices of 12
#: bytes make 264).  The bound only stops a corrupted LEN from making the scanner
#: wait for bytes that will never come; the CRC is what decides the frame.
DXL_MAX_FRAME = 520
#: FeeTech 56..70: the 12 control bytes plus counter and status, which is the
#: span the runtime reads in the shared `sync_read` (src/board.h FEE_BLOCK_*).
FEE_BLOCK_LEN = 15
FEE_BLOCK_CNT = 12
FEE_BLOCK_STATUS = 13
FEE_BLOCK_RESERVED = 14

# vendor window offsets (src/board.h V_*)
VOFF = {
    "magic_l": 0,
    "magic_h": 1,
    "cmd": 2,
    "sim_mode": 3,
    "amp_l": 4,
    "amp_h": 5,
    "freq_l": 6,
    "freq_h": 7,
    "report_frame": 8,
    "proto_lock": 9,
    "bias_x_l": 10,
    "bias_x_h": 11,
    "bias_y_l": 12,
    "bias_y_h": 13,
    "bias_z_l": 14,
    "bias_z_h": 15,
    "mirror_baud": 16,
    "dbg_level": 17,
    "status": 18,
    # Not reserved: the last protocol error this node refused or clamped
    # (DXL_ERR_*), which is where a refused write says why.  The reply's own
    # status byte is always 0 because FeeTech tooling reads a nonzero ack status
    # as a *servo* fault (src/board.h, V_LAST_ERR; src/fee.c).
    "last_err": 19,
}
VENDOR_MAGIC = 0x4D49

VCMD_NONE = 0
VCMD_SAVE = 1
VCMD_DEFAULTS = 2
VCMD_REBOOT = 3
VCMD_RESET_SIM = 4
VCMD_CONFIRM = 5
VCMD_BOOT = 6
VCMD_SWITCH_SLOT = 7

SIM_MODES = {
    0: "static",
    1: "sine",
    2: "drift",
    3: "noise",
    4: "spin",
    5: "sflp-wait",
    6: "frozen",
}
SIM_MODE_IDS = {v: k for k, v in SIM_MODES.items()}

TELEM_FLAG_BITS = {
    "sflp_valid": 0x01,
    "cnt_wrap": 0x02,
    "gyro_sat": 0x04,
    "sensor_err": 0x08,
    "simulated": 0x10,
    "frozen": 0x20,
    "cfg_dirty": 0x40,
    "fusion_ok": 0x80,
}

DXL_INST = {
    "ping": 0x01,
    "read": 0x02,
    "write": 0x03,
    "reg_write": 0x04,
    "action": 0x05,
    "factory_reset": 0x06,
    "reboot": 0x08,
    "clear": 0x10,
    "sync_read": 0x82,
    "sync_write": 0x83,
    "fast_sync_read": 0x8A,
    "bulk_read": 0x92,
}
FEE_INST = {
    "ping": 0x01,
    "read": 0x02,
    "write": 0x03,
    "reg_write": 0x04,
    "reg_action": 0x05,
    "recovery": 0x06,
    "sync_read": 0x82,
    "sync_write": 0x83,
    "reset": 0x0A,
    "cal": 0x0B,
}

# scales (src/board.h)
GYRO_MDPS_PER_LSB = 17.5
ACCEL_MG_PER_LSB = 0.122

# microduck's SflpDecoder::DEFAULT_MOUNT: trunk = [+raw_z, +raw_y, -raw_x]
DEFAULT_MOUNT = (
    math.sqrt(0.5),
    0.0,
    math.sqrt(0.5),
    0.0,
)


class ProtocolError(Exception):
    """A frame arrived but did not parse (CRC, length, id mismatch, ...)."""


# ── Dynamixel protocol 2.0 ──────────────────────────────────────────────────


def crc16_dxl(data: bytes) -> int:
    """ROBOTIS `update_crc`: poly 0x8005, init 0, MSB first, over the whole packet."""
    crc = 0
    for byte in data:
        crc ^= (byte << 8) & 0xFFFF
        for _ in range(8):
            if crc & 0x8000:
                crc = ((crc << 1) ^ 0x8005) & 0xFFFF
            else:
                crc = (crc << 1) & 0xFFFF
    return crc


def dxl_add_stuffing(data: bytes) -> bytes:
    """Insert protocol 2.0 byte stuffing: an extra 0xFD after any FF FF FD.

    Mirrors the official DynamixelSDK `addStuffing` (and rustypot's port): the
    pattern scan runs over the original bytes only, and `FF FF FF` keeps an
    `FF FF` suffix alive.
    """
    out = bytearray()
    run = 0
    for byte in data:
        out.append(byte)
        if run == 2 and byte == 0xFD:
            out.append(0xFD)          # stuffing byte
            run = 0
        elif byte == 0xFF:
            run = run + 1 if run in (0, 1) else 2
        else:
            run = 0
    return bytes(out)


def dxl_remove_stuffing(data: bytes) -> bytes:
    """Drop the 0xFD inserted after each FF FF FD (received body only)."""
    out = bytearray()
    run = 0
    for byte in data:
        if run == 3:
            run = 0
            if byte == 0xFD:
                continue                  # stuffing byte: drop it
        if run == 2 and byte == 0xFD:
            run = 3
        elif byte == 0xFF:
            run = run + 1 if run in (0, 1) else 2
        else:
            run = 0
        out.append(byte)
    return bytes(out)


def dxl_instruction(packet_id: int, instruction: int, params: bytes = b"") -> bytes:
    """FF FF FD 00 ID LEN_L LEN_H INST PARAM... CRC_L CRC_H (LEN = params + 3).

    The parameter region is byte-stuffed and LEN counts the stuffed bytes, which
    is what rustypot's `InstructionPacketV2::to_bytes` does.
    """
    params = dxl_add_stuffing(params)
    body = bytes([packet_id]) + struct.pack("<H", len(params) + 3) + bytes([instruction]) + params
    frame = b"\xFF\xFF\xFD\x00" + body
    return frame + struct.pack("<H", crc16_dxl(frame))


def dxl_ping(packet_id: int) -> bytes:
    return dxl_instruction(packet_id, DXL_INST["ping"])


def dxl_read(packet_id: int, addr: int, length: int) -> bytes:
    return dxl_instruction(packet_id, DXL_INST["read"], struct.pack("<HH", addr, length))


def dxl_write(packet_id: int, addr: int, data: bytes) -> bytes:
    return dxl_instruction(packet_id, DXL_INST["write"], struct.pack("<H", addr) + data)


def dxl_sync_read(ids: Sequence[int], addr: int, length: int) -> bytes:
    params = struct.pack("<HH", addr, length) + bytes(ids)
    return dxl_instruction(DXL_BROADCAST, DXL_INST["sync_read"], params)


def dxl_sync_write(ids: Sequence[int], addr: int, payloads: Sequence[bytes]) -> bytes:
    if not ids:
        raise ValueError("sync_write needs at least one id")
    width = len(payloads[0])
    params = struct.pack("<HH", addr, width)
    for pid, payload in zip(ids, payloads):
        if len(payload) != width:
            raise ValueError("all sync_write payloads must have the same width")
        params += bytes([pid]) + payload
    return dxl_instruction(DXL_BROADCAST, DXL_INST["sync_write"], params)


def dxl_fast_sync_read(ids: Sequence[int], addr: int, length: int) -> bytes:
    """The 0x8A instruction: byte for byte a SYNC_READ with a different opcode.

    The *answer* is not: the devices build one status packet between them (id
    `0xFE`), each appending `ERROR ID DATA CRC`, the CRC covering everything up to
    its own block - see [`dxl_parse_fast_sync_read`].  Nothing is byte-stuffed.
    """
    params = struct.pack("<HH", addr, length) + bytes(ids)
    return dxl_instruction(DXL_BROADCAST, DXL_INST["fast_sync_read"], params)


def dxl_fast_sync_block(pid: int, data: bytes, error: int = 0, upto: bytes = b"") -> bytes:
    """One device's contribution to a Fast Sync Read packet.

    `upto` is everything already on the wire (the prefix and the blocks ahead of
    this one); the CRC that ends the block covers it plus this block.
    """
    block = bytes([error, pid]) + data
    return block + struct.pack("<H", crc16_dxl(upto + block))


def dxl_parse_fast_sync_read(frame: bytes, ids: Sequence[int],
                             length: int) -> list[tuple[bytes, int]]:
    """Split an aggregate Fast Sync Read packet into `[(data, error), ...]`.

    Transcribed from rustypot 1.8's `parse_fast_sync_read_status_with_error`:
    every block's running CRC is checked (which is what pins the block positions)
    and the id in a block must be the one that was asked for in that slot.  Raises
    `ProtocolError` when anything does not line up.
    """
    block_size = length + 4
    if len(frame) != 8 + len(ids) * block_size:
        raise ProtocolError(f"aggregate length {len(frame)} != {8 + len(ids) * block_size}")
    if frame[4] != DXL_BROADCAST or frame[7] != 0x55:
        raise ProtocolError("aggregate packet must answer as 0xFE with 0x55")
    if struct.unpack_from("<H", frame, 5)[0] != len(frame) - 7:
        raise ProtocolError("aggregate LEN does not match the packet")
    out: list[tuple[bytes, int]] = []
    for i, pid in enumerate(ids):
        block = 8 + i * block_size
        crc_at = block + 2 + length
        if struct.unpack_from("<H", frame, crc_at)[0] != crc16_dxl(frame[:crc_at]):
            raise ProtocolError(f"block {i} CRC mismatch")
        if frame[block + 1] != pid:
            raise ProtocolError(f"block {i} is id {frame[block + 1]}, expected {pid}")
        out.append((bytes(frame[block + 2:crc_at]), frame[block]))
    return out


def dxl_parse_status(frame: bytes) -> tuple[int, int, bytes]:
    """Returns (id, error_byte, params).  Raises ProtocolError on a bad frame."""
    if len(frame) < 11:
        raise ProtocolError(f"status too short: {len(frame)}")
    if frame[0:4] != b"\xFF\xFF\xFD\x00":
        raise ProtocolError("bad header")
    if frame[7] != 0x55:
        raise ProtocolError(f"missing 0x55 status marker (got {frame[7]:#04x})")
    length = struct.unpack_from("<H", frame, 5)[0]
    if length != len(frame) - 7:
        raise ProtocolError(f"length mismatch: LEN={length} frame={len(frame)}")
    want = struct.unpack_from("<H", frame, len(frame) - 2)[0]
    got = crc16_dxl(frame[:-2])
    if want != got:
        raise ProtocolError(f"crc mismatch: got {got:#06x} want {want:#06x}")
    # body = error byte + parameters, byte-stuffed; de-stuff only after the CRC
    # (rustypot 1.6: `remove_stuffing(&data[8..msg_length - 2])`)
    body = dxl_remove_stuffing(bytes(frame[8:-2]))
    if not body:
        raise ProtocolError("empty status body")
    return frame[4], body[0], bytes(body[1:])


# ── FeeTech SCS/HLS ─────────────────────────────────────────────────────────


def fee_instruction(packet_id: int, instruction: int, params: bytes = b"") -> bytes:
    """FF FF ID LEN INST [ADDR DATA...] ~SUM, LEN = INST + params + SUM."""
    body = bytes([packet_id, len(params) + 2, instruction]) + params
    checksum = (~sum(body)) & 0xFF
    return b"\xFF\xFF" + body + bytes([checksum])


def fee_ping(packet_id: int) -> bytes:
    return fee_instruction(packet_id, FEE_INST["ping"])


def fee_read(packet_id: int, addr: int, length: int) -> bytes:
    return fee_instruction(packet_id, FEE_INST["read"], bytes([addr, length]))


def fee_write(packet_id: int, addr: int, data: bytes) -> bytes:
    return fee_instruction(packet_id, FEE_INST["write"], bytes([addr]) + data)


def fee_sync_read(ids: Sequence[int], addr: int, length: int) -> bytes:
    return fee_instruction(
        FEE_BROADCAST, FEE_INST["sync_read"], bytes([addr, length]) + bytes(ids)
    )


def fee_sync_write(ids: Sequence[int], addr: int, payloads: Sequence[bytes]) -> bytes:
    if not ids:
        raise ValueError("sync_write needs at least one id")
    width = len(payloads[0])
    params = bytes([addr, width])
    for pid, payload in zip(ids, payloads):
        if len(payload) != width:
            raise ValueError("all sync_write payloads must have the same width")
        params += bytes([pid]) + payload
    return fee_instruction(FEE_BROADCAST, FEE_INST["sync_write"], params)


def fee_parse_ack(frame: bytes) -> tuple[int, int, bytes]:
    """Returns (id, status, data)."""
    if len(frame) < 6:
        raise ProtocolError(f"ack too short: {len(frame)}")
    if frame[0:2] != b"\xFF\xFF":
        raise ProtocolError("bad header")
    length = frame[3]
    if length != len(frame) - 4:
        raise ProtocolError(f"length mismatch: LEN={length} frame={len(frame)}")
    if ((~sum(frame[2:-1])) & 0xFF) != frame[-1]:
        raise ProtocolError("checksum mismatch")
    return frame[2], frame[4], bytes(frame[5:-1])


# ── quaternion maths (same conventions as src/imu_math.c) ───────────────────


def half_to_float(bits: int) -> float:
    """IEEE 754 binary16 -> float."""
    sign = -1.0 if bits & 0x8000 else 1.0
    exponent = (bits >> 10) & 0x1F
    fraction = bits & 0x3FF
    if exponent == 0:
        return sign * fraction * 2.0 ** -24
    if exponent == 0x1F:
        return sign * math.inf if fraction == 0 else math.nan
    return sign * (1.0 + fraction / 1024.0) * 2.0 ** (exponent - 15)


def float_to_half(value: float) -> int:
    """Round-to-nearest-even float -> binary16 (used by the self tests)."""
    import numpy as np  # only for the self test; not needed at runtime

    return int(np.float16(value).view(np.uint16))


def q_mul(a: Sequence[float], b: Sequence[float]) -> tuple[float, float, float, float]:
    aw, ax, ay, az = a
    bw, bx, by, bz = b
    return (
        aw * bw - ax * bx - ay * by - az * bz,
        aw * bx + ax * bw + ay * bz - az * by,
        aw * by - ax * bz + ay * bw + az * bx,
        aw * bz + ax * by - ay * bx + az * bw,
    )


def q_conj(q: Sequence[float]) -> tuple[float, float, float, float]:
    return (q[0], -q[1], -q[2], -q[3])


def q_normalize(q: Sequence[float]) -> tuple[float, float, float, float]:
    n = math.sqrt(sum(c * c for c in q))
    if n <= 0.0:
        return (1.0, 0.0, 0.0, 0.0)
    return tuple(c / n for c in q)  # type: ignore[return-value]


def q_rotate(q: Sequence[float], v: Sequence[float]) -> tuple[float, float, float]:
    """v' = q v q⁻¹"""
    w, x, y, z = q
    t = (
        2.0 * (y * v[2] - z * v[1]),
        2.0 * (z * v[0] - x * v[2]),
        2.0 * (x * v[1] - y * v[0]),
    )
    c = (
        y * t[2] - z * t[1],
        z * t[0] - x * t[2],
        x * t[1] - y * t[0],
    )
    return (
        v[0] + w * t[0] + c[0],
        v[1] + w * t[1] + c[1],
        v[2] + w * t[2] + c[2],
    )


def q_rotate_inv(q: Sequence[float], v: Sequence[float]) -> tuple[float, float, float]:
    """v' = q⁻¹ v q"""
    w, x, y, z = q
    t = (
        2.0 * (y * v[2] - z * v[1]),
        2.0 * (z * v[0] - x * v[2]),
        2.0 * (x * v[1] - y * v[0]),
    )
    c = (
        y * t[2] - z * t[1],
        z * t[0] - x * t[2],
        x * t[1] - y * t[0],
    )
    return (
        v[0] - w * t[0] + c[0],
        v[1] - w * t[1] + c[1],
        v[2] - w * t[2] + c[2],
    )


def euler_from_quat(q: Sequence[float]) -> tuple[float, float, float]:
    """ZYX (yaw-pitch-roll) in degrees, for display only."""
    w, x, y, z = q
    sinr_cosp = 2.0 * (w * x + y * z)
    cosr_cosp = 1.0 - 2.0 * (x * x + y * y)
    roll = math.atan2(sinr_cosp, cosr_cosp)
    sinp = 2.0 * (w * y - z * x)
    pitch = math.copysign(math.pi / 2, sinp) if abs(sinp) >= 1 else math.asin(sinp)
    siny_cosp = 2.0 * (w * z + x * y)
    cosy_cosp = 1.0 - 2.0 * (y * y + z * z)
    yaw = math.atan2(siny_cosp, cosy_cosp)
    return (math.degrees(roll), math.degrees(pitch), math.degrees(yaw))


# ── the block, decoded ──────────────────────────────────────────────────────


@dataclass
class ImuBlock:
    """One 20-byte block, still in the chip frame."""

    gyro_raw: tuple[int, int, int]
    quat_half: tuple[int, int, int]
    accel_raw: tuple[int, int, int]
    counter: int
    flags: int

    @classmethod
    def decode(cls, data: bytes, protocol: str = PROTO_DXL) -> "ImuBlock":
        """Decode one block.

        Two wire shapes exist (src/board.h, docs/bus_timing_borrow_plan.md):

          * the FeeTech 56..70 *contract* block, 15 bytes: the 12 control bytes
            plus the sample counter and the status flags.  That is the span the
            runtime reads from the IMU node and from every servo in one
            `sync_read`, so the counter and status have to live inside it, and
            the raw accelerometer does not fit (it is in the 128 alias);
          * the 20-byte diagnostic block at FeeTech 128 / Dynamixel 124, which
            adds the raw accelerometer.
        """
        if (protocol == PROTO_FEE) and (len(data) == FEE_BLOCK_LEN):
            g = struct.unpack_from("<hhh", data, 0)
            h = struct.unpack_from("<HHH", data, 6)
            return cls(g, h, (0, 0, 0), data[FEE_BLOCK_CNT], data[FEE_BLOCK_STATUS])

        if len(data) < CTRL_LEN:
            raise ProtocolError(f"block too short: {len(data)}")
        padded = bytes(data) + bytes(max(0, TELEM_LEN - len(data)))
        g = struct.unpack_from("<hhh", padded, 0)
        h = struct.unpack_from("<HHH", padded, 6)
        a = struct.unpack_from("<hhh", padded, 12)
        return cls(g, h, a, padded[18], padded[19])

    @property
    def gyro_dps(self) -> tuple[float, float, float]:
        return tuple(g * GYRO_MDPS_PER_LSB / 1000.0 for g in self.gyro_raw)  # type: ignore

    @property
    def gyro_rad(self) -> tuple[float, float, float]:
        return tuple(math.radians(g) for g in self.gyro_dps)  # type: ignore

    @property
    def accel_mg(self) -> tuple[float, float, float]:
        return tuple(a * ACCEL_MG_PER_LSB for a in self.accel_raw)  # type: ignore

    @property
    def quat_xyz(self) -> tuple[float, float, float]:
        return tuple(half_to_float(h) for h in self.quat_half)  # type: ignore

    @property
    def quat_raw(self) -> tuple[float, float, float, float]:
        x, y, z = self.quat_xyz
        return (math.sqrt(max(0.0, 1.0 - (x * x + y * y + z * z))), x, y, z)

    @property
    def quat_valid(self) -> bool:
        return bool(self.flags & TELEM_FLAG_BITS["sflp_valid"])

    def flag_names(self) -> list[str]:
        return [name for name, bit in TELEM_FLAG_BITS.items() if self.flags & bit]
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

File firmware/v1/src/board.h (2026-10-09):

/*!
    \file    board.h
    \brief   imu_to_dxl v1 - board wiring, clocking and build-time options

    Target: GD32F303CC (LQFP48, 256 KB flash / 48 KB SRAM), 12 MHz HXTAL,
            system clock 120 MHz - see src/system_gd32f30x.c.

    The board is the reverse-engineered `imu_to_dxl` node: an LSM6DSV16X on SPI0
    that publishes a 12-byte gyro+SFLP-quaternion block as a Dynamixel node
    (ID 200, control-table address 124) on the shared motor bus.

    v1 runs on a bare GD32F303CC development board, so:
      * the SPI IMU is not fitted - src/imu_sim.c synthesises the sensor block;
      * USART1 (PA2/PA3) is the real motor bus and stays wired as such;
      * USART0 (PB6/PB7, on the host as /dev/ttyUSB0) doubles as the debug
        console AND as a bus mirror, so the PC test tool can exercise the
        protocol before the real PCBA comes back.  See BUS_MIRROR_ENABLE.

    Pin map (final hardware, `elec_imu_to_dxl/imu_to_dxl/imu_to_dxl.kicad_sch`):

      PA2  USART1_TX   motor bus, half duplex through the auto-direction
                       buffer (TXD_EN is generated from TX, no GPIO involved)
      PA3  USART1_RX   motor bus receive
      PA4  SPI0_NSS    IMU chip select (active low)
      PA5  SPI0_SCK    IMU clock
      PA6  SPI0_MISO   IMU data out
      PA7  SPI0_MOSI   IMU data in
      PB0  INT1        IMU interrupt 1
      PB1  INT2        IMU interrupt 2
      PB6  USART0_TX   debug / bus mirror (host: /dev/ttyUSB0)
      PB7  USART0_RX   debug / bus mirror
      PB5  LED         development-board indicator (STATUS_LED_ENABLE)
*/

#ifndef BOARD_H
#define BOARD_H

#ifdef IMU_TO_DXL_HOST_TEST
/* Host-side protocol tests (host/tools/test_protocols.c) compile dxl2.c, fee.c
   and imu_sim.c with gcc, where the GD32 headers do not exist.  Only plain
   integer types are needed there. */
#include <stdint.h>
#else
#include "gd32f30x.h"
#endif

/* ── firmware identity ───────────────────────────────────────────────────── */

#define FW_VERSION_MAJOR    1
#define FW_VERSION_MINOR    0
/* one byte, high nibble = major, low nibble = minor - the Dynamixel
   "firmware version" register format */
#define FW_VERSION_BYTE     ((FW_VERSION_MAJOR << 4) | (FW_VERSION_MINOR & 0x0F))
#define FW_BUILD_NAME       "imu_to_dxl v1"

/* ── build-time options (all overridable from CMake) ─────────────────────── */

/* Debug console on USART0.  0 compiles the whole dbg layer out. */
#ifndef DBG_ENABLE
#define DBG_ENABLE              1
#endif

/* USART0 (PB6/PB7) is the *debug console* and nothing else: it prints DBG_*
   lines so a problem can be found.  Every bus transaction - the register
   protocol and the field upgrade - belongs to USART1 (PA2/PA3), the single
   wire motor bus this node shares with the servos (`docs/upgrade.md` §1,
   `docs/imu_to_dxl_protocol.md` §2).

   1 -> bench only.  USART0 also answers protocol frames, so a development
        board with no motor bus wired yet can be driven over /dev/ttyUSB0.
        A host must then still point the upgrade tool at the bus it means to
        use: everything the protocol can do, this port can do too. */
#ifndef BUS_MIRROR_ENABLE
#define BUS_MIRROR_ENABLE       0
#endif

/* PB5 status LED, active high.  Only the development board has it. */
#ifndef STATUS_LED_ENABLE
#define STATUS_LED_ENABLE       1
#endif

/* Persist ID / baud / simulation settings into the last flash page. */
#ifndef CFG_FLASH_ENABLE
#define CFG_FLASH_ENABLE        1
#endif

/* Read the MCU internal temperature sensor (ADC0 channel 16) for the
   `present temperature` register. */
#ifndef TEMP_SENSOR_ENABLE
#define TEMP_SENSOR_ENABLE      1
#endif

/* Sensor source.  1 = the LSM6DSV16X on SPI0 (the real PCBA, since 2026-09-25);
   0 = src/imu_sim.c, which keeps working with no chip fitted and is what the
   bench smoke test's simulation modes exercise.  The block, the units and the
   flags are identical either way - src/imu.c is the only file that knows. */
#ifndef IMU_USE_SPI
#define IMU_USE_SPI             1
#endif

/* ── FeeTech personality (build-time; docs/imu_to_dxl_protocol.md §16) ─────
   native = this repository's own contract; ft6 = byte-compatible with the FT6
   node contract (Microduck-kissqy `firmware/imu-source`), which is what the
   released R17 host (`duck-control/src/feetech.rs`) insists on.

   This cannot be a runtime choice: the 15-byte block at 56..70 has no spare
   room, bit 0 of its status byte means "has data" in one contract and "no data"
   in the other, and the host refuses to open the bus at all when the identity
   registers do not match.  The choice is therefore made where the host's is
   made - at build time.

   Only the FeeTech map moves.  The Dynamixel map, protocol 2.0, the bus timing,
   the bootloader and the upgrade protocol are identical in both builds; that is
   asserted by host/tools/test_regmap.c, not assumed. */
#ifndef FEE_IMU_PERSONALITY_FT6
#define FEE_IMU_PERSONALITY_FT6 0
#endif
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

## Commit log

2026-09-27 Initial commit: Microduck reverse-engineered design
    [bom(hq).csv, bom.csv, designators.csv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]
2026-09-27 更新readme
2026-09-27 Fix: convert banana_pcb from submodule to normal directory
    [banana_pcb.kicad_pcb, banana_pcb.kicad_sch]
2026-09-27 update: readme
    [bom(hq).csv, bom.csv, imu_to_dxl.kicad_sch]
2026-09-27 update: BOM
    [bom.csv, dxl_hub.kicad_pcb, dxl_hub.kicad_sch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]
2026-09-27 host: draw the board in its mounted frame (apply DEFAULT_MOUNT); serve web assets no-store
2026-09-29 firmware: 调试口只输出日志，USART0 不再解析总线帧
    - BUS_MIRROR_ENABLE 默认 0：USART0 是 115200 的 DBG_* 控制台，不再解析任何总线帧；
    台架构建（-DBUS_MIRROR_ENABLE=1）仍可把它当第二个协议口。
    - boot 模式不再把 USART0 的收包时间戳算作"主机还在"：镜像未开时，有人在调试终端
    打字会把节点一直留在 boot 模式，越过 BOOT_IDLE_EXIT_MS。
    - 统计行打印 console=<端口实际波特率>，不再打印配置里的镜像波特率（它显示 1000000，
    而端口实际跑 115200）。
    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
2026-09-29 host: 探测并占用电机总线，再开始升级
    - upgrade.py 的 --port 默认 auto：逐个探测 ttyACM0-1、ttyUSB0-5、ttyS2，取第一个
    真能应答节点的设备。USB-TTL 适配器按行为找到，不按名字排除；打不开或不应答的
    候选跳过，全都不通时逐条列出原因。
    - 拒绝和别人抢端口（机器人上是 robotd），打印 stop/upgrade/start 顺序；robotd 的
    socket 在、但描述符读不到时给 warning；升级结束后提醒交还总线。
    - build.sh：升级路径 BUS_PORT 默认 auto，smoke/web 仍用具体设备；构建时打印生效的
    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
2026-09-29 docs: 机器人上升级路径，以及路径与引用卫生
    - upgrade.md 新增 §4.5（机器人上升级：/dev/ttyS2、先停 robotd）与 §9.1（改动前后
    走电机总线的对照实测：1545 块、0 重传、3.23 s，两边一致，免得有人再往固件里加
    端口检查）。
    - UPG_BLKLEN 是 4..16 且 4 的倍数，不是 1..16；file:line 引用随源码重排重新锚定；
    去掉引用台架临时产物的措辞。
    - 清理绝对路径与私有路径：规格书引用、注释与补丁里的私有仓库名、网页标题；
    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
2026-09-29 同步更新上游microduck源码和飞特补丁
2026-09-30 更新原理和PCB，优化飞特舵机上拉电阻小导致小概率丢包问题
    [bom.csv, designators.csv, imu_to_dxl.kicad_pcb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]
2026-09-30 更新支持批量初始化舵机
2026-09-30 feetech: 真机首跑修两处启动缺陷，并记录增益实测
    第一次把打补丁的 robotd 跑在 15 舵机 + IMU 节点上，由此修两处、记一批数据：
    - bus.rs：open() 打开端口后等 OPEN_SETTLE = 400 ms。实测连续 4 次冷启动，
    每一次都丢掉普查里第一个 id（20）的 ping，于是 15 台里少一台 → 被当成
    "换了舵机" → 进收养流程找出厂 id 1 → 失败重试，白等十几秒。host/bus.py
    早就有同一常数（OPEN_SETTLE_S = 0.35），注明就是为这块板测的。
    - bus.rs：普查里同一个 id ping 两次才算缺失。缺失会触发破坏性的改址动作，
    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
2026-09-30 hls_debugger: 初始化写入安全的位置环增益（Kp 32 / Kd 0）
    批量初始化原本不写增益，舵机出厂 EPROM 的 P/D 是厂商默认的 32/40，而
    robotd 启动后会用 robotd.toml 的 gain 覆盖 RAM 50 —— 那份默认值 200 是给
    XL330 的 0..16383 标度调的，在飞特 0..254 上是顶格。
    真机实测（HD-1910-C001，15 台装在悬空鸭子上，只改这一个数值）：
    Kp=200：left_hip_yaw 自激振荡，峰值电流 4966-5388 mA、目标不动时自报速度
    4.37 rad/s、壳温升到 74 °C 且持续上升、人耳听到剧烈抖动；
    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
2026-09-30 host: 新增示波器用的总线流量发生器 scope_traffic.py
    示波器需要的是"一个已知帧、按固定速率无限重复"：servo_probe.py 是固定序列、
    bus_smoke.py 判 pass/fail、robotd 每 tick 帧都不同，三个都不适合触发。工具
    只在需要时才有意义，所以单独成一个。
    - 五种模式：ping（单个 6 字节帧，最干净的触发源）、sync（机器人真实的一个 tick，
    广播 SYNC_READ 16 个设备）、sync-pos（15 关节、每台 2 字节）、write（广播
    SYNC_WRITE，把每台写回它当前的位置，帧是真的但不会动，需 --confirm-motion-safe）、
    idle（不发，用来量空闲电平与上拉）。
    - 启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
2026-09-30 优化了microduck飞特舵机适配源码
2026-09-30 firmware: 支持 Dynamixel Fast Sync Read (0x8A)，并修掉解析期丢字节
    上游 microduck 默认 bus.fast_sync_read = true，普通 sync_read 走 0x8A；本条
    ID 列表里的任何一台设备不支持它，整组 16 设备的读都会超时，而 IMU 节点此前只
    实现 0x82。
    - 0x8A 聚合应答（src/dxl2.c "fast sync read"）：
    LEN = 1 + N×(X+4) 覆盖整包、每段 ERR + ID + DATA + 累积 CRC、**不做字节填充**、
    第 0 台设备发 8 字节前缀；本节点在第 k 位时按前面 k 段的**字节数**让位（一段
    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
2026-09-30 host: 0x8A 自检把"主机侧丢帧"与"节点不应答"分开
    --repeat 循环原来一遇到没回复就抛 TimeoutError 栈并判失败。实测（同一次 50 发）：
    主机侧丢 1 条回复，而节点自己的计数是 frames/answered 各 +50、tx +1200 = 50×24，
    即 50 条全部应答——就是协议文档 §12 第 8 项记录的 USB 适配器整块丢回复，与节点无关。
    现在统计丢帧率、最多容忍 5%（至少 1 条），并在失败信息里提示先去对节点的
    `answered` 计数再下结论。
2026-09-30 docs: 清掉指向仓库外文件的引用，并写明 v1/ 是固件唯一真源
    公开仓库里有两类"读者找不到"的引用：
    1. dev 树（soft_imu_to_dxl/v1）独有的两份文档被当成仓库内文档引用——
    `docs/real_robot_runbook.md`（8 处）与 `docs/roadmap_lsm6ds3trc.md`（3 处）。
    现在把结论直接写进正文（例如 USB 适配器整块丢回复那组数字，就在
    `bus_timing_borrow_plan.md §7.7`；方向盘、`TELEM_FLAG_*` 语义指向协议文档 §6.4），
    并从 README 的文档清单里去掉了这两条。
    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
2026-09-30 固件版本号升级为1.5.0
2026-10-01 更新README.md固件升级方法
2026-10-01 fix(gitignore): 恢复被通用忽略规则误伤的源码，修好开箱编译
    根 .gitignore 与 software/.gitignore 直接套用了多语言模板，其中三条规则
    对「Rust + 固件」仓库过宽，且按**目录名**匹配，导致 11 个源码/配置文件
    从未进入版本库：
    - `*.d` 同时匹配以 `.d` 结尾的目录，吃掉 btd/configd/mediad/padd/tof/updater
    的 systemd/sysusers.d/*.conf，以及 deploy/journald.conf.d/
    - `bin/` 匹配任意层级的 bin 目录，吃掉 duck-detect/src/bin/duck-bench.rs
    与 pet-detect/src/bin/{detect,features}.rs
    - `*.bin` 吃掉 robotctl/assets/duck.bin（robotctl 要读的源码资产）
    后果是 clone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
2026-10-01 docs: 新增 software/编译方法.md
    记录 microduck_feetech 的编译、测试与上车流程：
    - 本机测试循环与交叉编译循环的区别 —— 前者秒级、不需要板子，但**不能**带
    交叉环境变量，否则 aarch64 的库路径会进到 x86 链接里
    - 受限网络下 crates.io（source replacement）与 Debian 源（DUCK_DEBIAN_MIRROR）
    的镜像配置，以及「依赖缓存命中后可完全离线构建」
    - aarch64 sysroot 的生成、它导出的四个变量，以及 sysroot 路径会进入
    RUSTFLAGS 指纹、换路径即全量重编译
    - 板子强制验签，因此需要自建 dev 密钥：xtask keygen 生成、公钥以 .dev.pub
    结尾装进 trus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
2026-10-02 更新README.md增加微信群二维码
2026-10-02 fix(bus): 去掉每笔串口事务的 tcdrain，控制环 36.3 → 50.0 Hz
    serialport 的 flush() 就是 tcdrain，而这个分支在每笔写之后都调它
    （6 处）。真机实测（Radxa Zero 3W 的 ttyS2，每种帧型 30 次）它是
    一个固定 ~12 ms，与帧长无关也与有没有设备应答无关：
    8 B 12.08 ms 9 B 10.82 ms 24 B 11.23 ms（16 设备应答）
    24 B 12.69 ms（无人应答） 56 B 12.69 ms
    8 字节在 1 Mbps 上只有 80 µs，所以这 12 ms 是驱动在报告发送器已空，
    不是总线。每 tick 读+写两笔就是 ~25 ms，而周期只有 20 ms：控制环
    上限 ~41 Hz，实测 36.3 Hz，`missed` 占 48%，更新健康门判不健康。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
2026-10-02 fix(bus): burst 静默判据 2 ms → 4 ms，把尾部余量补回来
    一次 16 设备广播读的相邻应答间隔，在真机上量了 9000 个 tick（50 Hz、
    带目标 sync_write 的完整 tick 形状、30 ms 收集窗口不截断）：
    median 0.27 ms p99 0.57 ms max 1.94 ms (n = 135000)
    2 ms 在这个样本里仍然撑住了（9000/9000 tick 收齐），但最坏间隔占掉了
    预算的 97%；把判据收到 1 ms，同样这 9000 个 tick 里立刻有 26 个失败。
    这条尾巴离门槛只剩一步，舵机、接插件或温度的任何余量损失都会变成那个
    孤立的 `id(s) … missing`，循环把它记成失败 tick 并 coast 过去。
    掉读率与这个机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
2026-10-02 fix(firmware): 让 DBG_ENABLE=0 真的能编译，并关掉调试控制台
    DBG_ENABLE=0 从来没有编译过：dbg.h 的 #else 分支定义了
    `#define dbg_hex(...) ((void)0)`，而 dbg.c:67 又真的定义了同名函数
    （它自己已经有 #if DBG_ENABLE 的函数体保护），于是函数式宏把它自己的
    定义改写成 `void ((void)0)`：
    src/dbg.c:67: error: expected identifier or '(' before 'void'
    而这个宏没有任何调用点（grep 不到 dbg_hex 的调用），真正的接口是
    DBG_ERROR / DBG_INFO / DBG_TRACE 三个可变参数宏。删掉它即可——
    "把代码去掉"由函数体的 #if 保护负责。
    同时版本号 1.5.0 → 1.5.1，并关掉控制台。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
2026-10-02 chore: 同步上游 main 的 10 个提交；4656690 的零点检查刻意不带
    从基线 f0d934e 起上游 main 有 10 个提交 / 19 个文件 / +356 −84，现已
    全部并入，净效果 +311 / −83。19 个文件里只有两个属于 duck-control。
    唯一需要判断的是 4656690「an adopted knee gets its homing offset」：它把
    每颗舵机应有的零点偏移加进 check_registers_of，值取自 microduck_runtime 的
    setup_motor_rpi.py —— 膝 (13, 23) 为 −512、其余为 0 —— 而那个检查会
    **写**它认为不对的寄存器。
    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
2026-10-02 docs(fork): 记录移植改动量、与上游的差距与两条边界
    把与上游的差异量化下来，供后来者与 rebase 时判断。
    方法：git archive f0d934e 导出干净树，与本目录（去掉 target/ 等未跟踪
    产物）逐文件对比。结论：**17 个文件 +2416/−622 就是移植本身**。其中
    bus.rs + feetech.rs 占新增行的 90%；除这两个文件和本页外，其余 14 个文件
    合计只有 +164/−225，且一半以上是注释或文档，Cargo.lock 是净减少
    （rustypot 整棵树消失）。当天那两处总线修复另占 2 文件 +39/−39 且行数净零，
    所以总量不变 —— diff 的行数在三份版本之间不可相加，文中已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
2026-10-03 更新firmware/v1/patches有关的一些说明文件
2026-10-03 优化舵机调试软件功能hls_servo_debugger
2026-10-06 最新优化同步
2026-10-09 feat(fee): FT6 兼容人格编译开关，默认 ft6 + 本板安装朝向补偿
    同一个固件现在能编译出两种飞特侧线协议人格，由 FEE_IMU_PERSONALITY
    (=FEE_IMU_PERSONALITY_FT6) 选择；默认 ft6，因为目标机器人跑的是
    R17/robotd，它的身份门要求 200@0/5 == 06 00 00 00 F2。
    只动 FeeTech 侧：Dynamixel(协议 2.0)、总线时序、bootloader、升级协议、
    配置页两种人格完全一致，并由测试断言（见下一个提交）。
    - 身份：FeeTech 0/1 = 6/0、3/4 = 0xF200（native 仍是 1.0 / 0x4D49）。
    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
2026-10-09 test(fee): 寄存器镜像金标、FT6 布局与朝向补偿的宿主机测试
    新增 host/tools/test_regmap.c：在 PC 上跑真实的 src/dev.c（flash 用
    boot_flash.c 的 RAM 镜像、ADC 编译掉、CMSIS 临界区桩掉），导出 0..255
    寄存器镜像，因此不需要台架就能证明"没用别的 bug"和"协议 2.0 没被动过"：
    - native 构建的 FeeTech 镜像 0..255 与改动前捕获的金标逐字节相同；
    - ft6 构建的 Dynamixel 镜像同样与 native 金标逐字节相同（这是硬要求）；
    - ft6 映射：身份 06 00 00 00 F2 C8 00、契约块 68/69、124..143 诊断块、
    196..215 原始 20 字节块、以及 71..123/144..147/216..255 为空；
    - 读时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
    [bus.py, test_protocols.c]
2026-10-09 docs(fee): 记录飞特人格开关、FT6 映射与安装朝向补偿
    docs/imu_to_dxl_protocol.md 新增 §16：两种人格的完整 FeeTech 寄存器映射
    (native/ft6 对照)、契约块 68/69 的 ft6 语义与状态位表、R17 主机判据
    (raw[13]&0xF0==0、ready=(raw[13]&0x07)==0、连续 3 次同序号判 stale)、
    124..143 诊断块布局、语义对照表、实现与验证位置；§16.7 专门写安装朝向
    补偿（含用实测数据推出"绕芯片 Z 180°"的过程、gravity≈(0,0,-1) 的验收
    判据、以及主机侧 verify-imu 的替代做法）。
    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
2026-10-09 Firmware:可通过FEE_IMU_PERSONALITY宏开关切换FT6协议或原有协议
2026-10-09 hardware:升级dxl_hub。左右腿飞特舵机线移动到背面，解决与脖子舵机略微干涉放不到底的问题
    [dxl_hub.kicad_pcb, dxl_hub.kicad_sch]
2026-10-10 update dxl_hub
    [dxl_hub.kicad_pcb]
2026-10-19 update bom
2026-10-19 更新dxl_hub螺丝规格
2026-10-20 hardware/dxl_hub: 略微扩大接线孔
